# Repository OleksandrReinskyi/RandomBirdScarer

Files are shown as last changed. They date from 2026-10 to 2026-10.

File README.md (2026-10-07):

# Autonomiczny Stochastyczny Odstraszacz Ptaków

> Autor: Oleksandr Reinskyi
> 
## 1. Opis zasady działania
**Cel:** W gospodarstwie moich rodziców znajduje się plantacja leszczyny. Jednym z głównych zagrożeń dla orzechów są ptaki. Odstraszacze wykorzystujące pasywny czujnik podczerwieni okazują się nieskuteczne w warunkach sadu, z kolei inne rozwiązania są zbyt drogie. Dlatego właśnie powstał ten projekt. Opracowane urządzenie dąży do eliminacji zjawiska przyzwyczajania się szkodników do powtarzalnego dźwięku dzięki zastosowaniu sygnałów generowanych losowo.

System składa się z trzech głównych modułów:
1. **Moduł zasilania:** Pakiet 3 ogniw Li-Ion 3.7V
2. **Płytka stochastycznego kontrolera:** Układ analogowo-cyfrowy generujący losowe interwały załączania płytki generatora dźwięku.
3. **Płytka generatora dźwięku:** Układ wytwarzający falę prostokątną o częstotliwości 2,1–2,9 kHz, która trafia na glośnik.

Schemat blokowy systemu

W tym repozytorium znajduje się projekt płytki stochastycznego kontrolera.

---

### Zasada działania sterownika:

1. Dioda Zenera pracująca w stanie przebicia lawinowego generuje analogowy szum biały.
2. Niewielkie fluktuacje szumu są wzmacniane przez wzmacniacz operacyjny TL072 (wzmocnienie $A_u \approx 511$), a następnie przekształcane przez komparator LM393 na  ciąg impulsów, podawany na wejście danych $D$ przerzutnika typu D (HEF4013B).
3. * **Timer 1:** Generuje krótkie impulsy co 5 minut.
   * **Timer 2:** Odpowiada za taktowanie krótkich cykli dźwięku (co ok. 5–10 sekund)
4. Przebiegi z obu timerów są podawane przez diodową bramkę logiczną OR na wejście zegarowe $CLK$ przerzutnika.
5. Wyjście proste $Q$ steruje wejściem zerowania ($RESET$) Timera 2, decydując o zakończeniu lub wydłużeniu cyklu odstraszania.
6. Wyjście zanegowane $\overline{Q}$ steruje bramką tranzystora P-MOSFET, który załącza napięcie zasilania dla płytki generacji dźwięku.

Urządzenie załącza się w nieprzewidywalnych odstępach czasu będących wielokrotnością 5 minut (np. 5, 10, 15 min...) na losowy czas trwania będący wielokrotnością 10 sekund (np. 10, 20, 30 s...), co redukuję adaptację ptaków do sygnału. 

> **Uwaga:** Na potrzeby symulacji w LTspice oraz demonstracji wideo, wartości elementów $RC$ w generatorach czasowych zostały przeskalowane w dół, redukując okresy do odpowiednio **~20 s** (zamiast 5 min) oraz **~5 s** (zamiast 10 s)

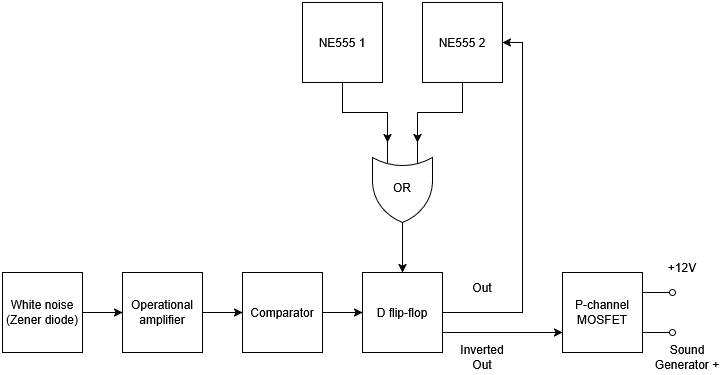
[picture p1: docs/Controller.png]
SchematIdeowy


---

## 2. Realizacja

### Wyniki symulacji (LTspice)
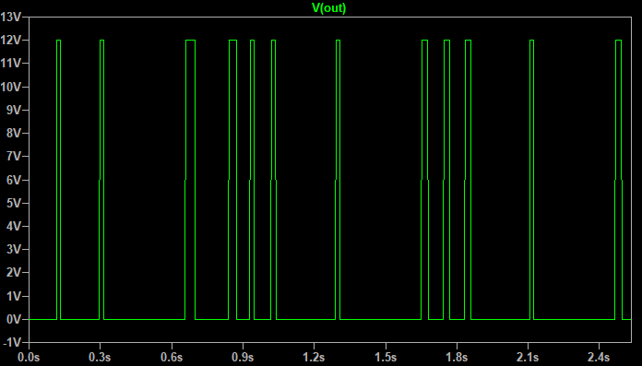
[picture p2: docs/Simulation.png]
Symulacja układu w LTspice


### Obudowa (FreeCAD)
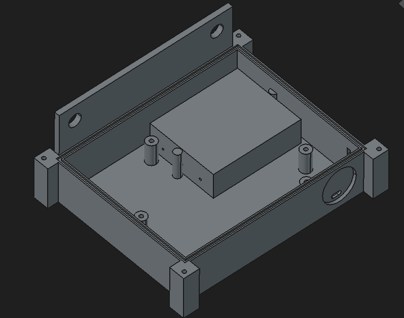
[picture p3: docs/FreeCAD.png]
Projekt obudowy w FreeCAD


### Demonstracja wideo
[Link](https://www.youtube.com/watch?v=rtPFrEMRT7Q)

### Zmontowany prototyp
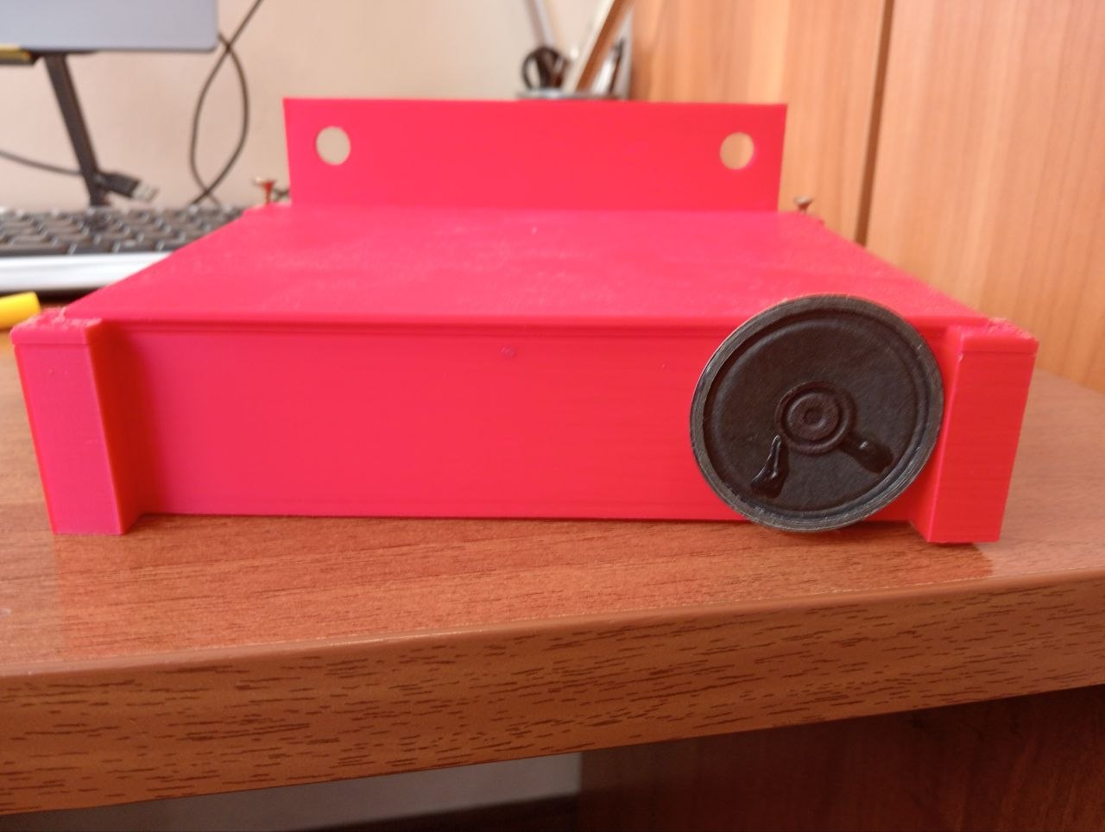
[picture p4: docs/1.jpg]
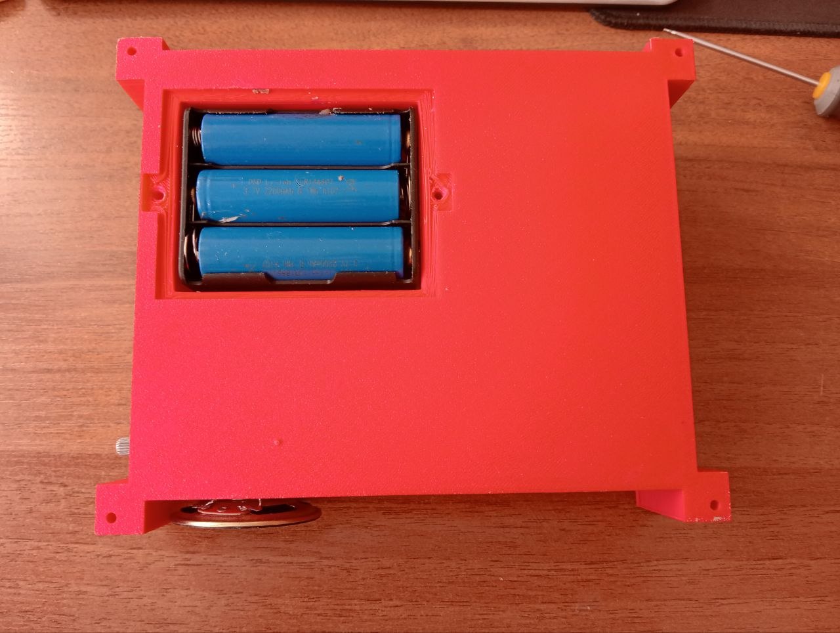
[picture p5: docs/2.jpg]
|  |  |
|--|--|
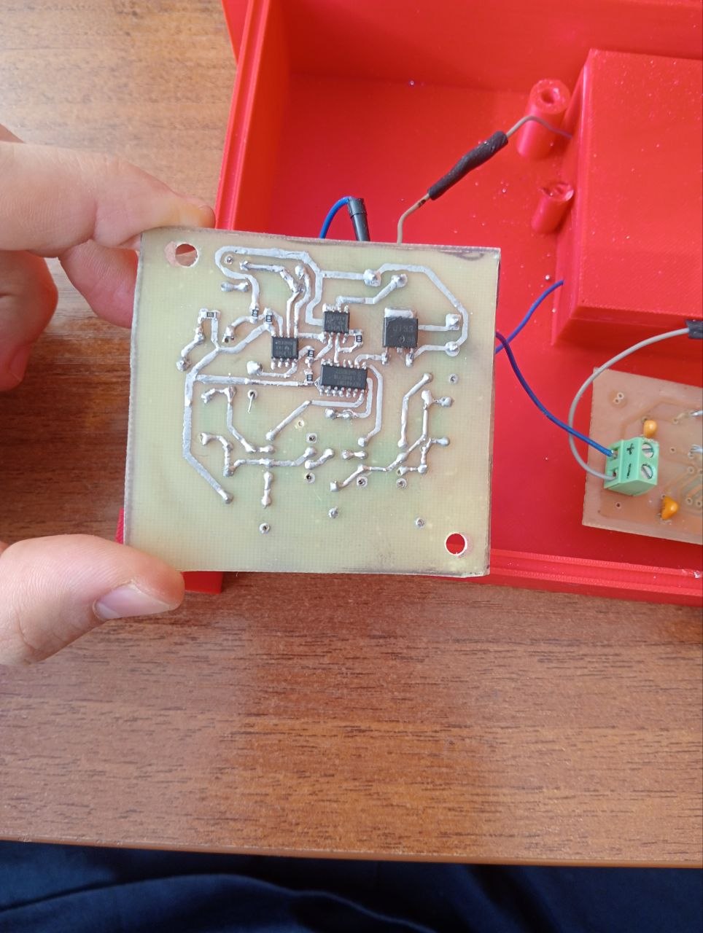
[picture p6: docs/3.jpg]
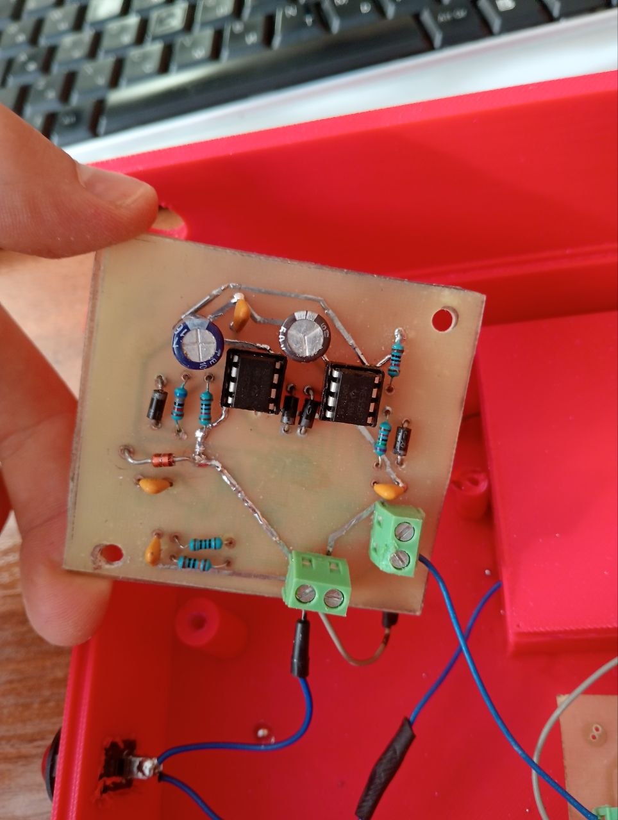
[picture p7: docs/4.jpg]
|  |  |

## 3. Problemy i napotkane trudności 

### Zidentyfikowane problemy:
* Brak hermetyczności obudowy. Wykonano ją z plastiku niskiej jakości i pozbawiono dedykowanych uszczelek.
* Ograniczony czas pracy. Zgodnie z obliczeniami urządzenie może pracować maksymalnie do 3 dni, po czym akumulatory wymagają ponownego naładowania. Również  brakuje modułu kontroli ładowania  (3S BMS)

### Napotkane trudności:
#### 1. Symulacja 
* Najpierw prowadziłem symulację stosując idealne modele elementów, co dawało wyniki niezgodne z rzeczywistością. Zamieniłem je na modele wybranych komponentów dla LTSpice.
* Najpierw nie stosowałem kondensatorów odsprzęgających i dlatego wzmacniacz ciągle wchodził w nasycenie. 
#### 2. Projektowanie płytki w KiCAD
* Jako PMOS użyłem najpierw symbolu o kolejności pinów DGS, a footprintu o kolejności pinów GDS, co spowodowało, że sygnał sterujący pojawiał się na Drain zamiast Gate.
* Nie zauważyłem, że LM393 ma otwarty kolektor i dlatego na wejściu Data HEF4013B zawsze było 0V.
* Na dolnej stronie płytki użyłem sterf wypełnionych miedzią jako węzłów dla +12v oraz GND. To sprawiło, że lutowanie lutownicą o małej mocy stało się niemożliwe, bo lut zastygał natychmiastowo.
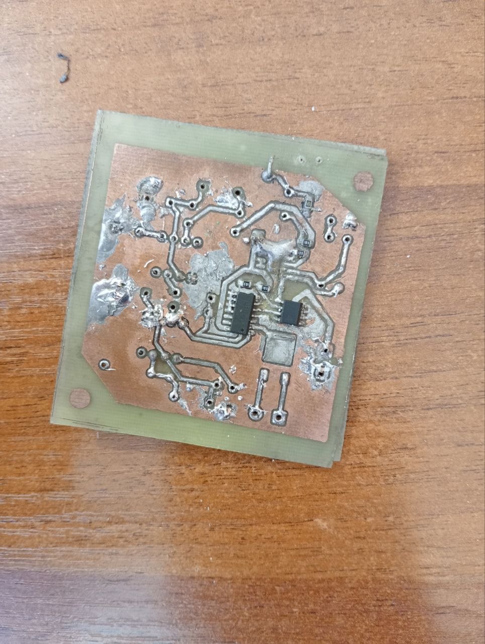
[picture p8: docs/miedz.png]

#### 3. Testowanie
* TL072 niedostatecznie wzmacniał sygnał z diody Zenera i dlatego komparator nie reagował na niego. Zwiększyłem wartości rezystorów, żeby wzmocnienie wynosiło około 500.
* Zauważyłem, że NE555 mocno się grzeją. Okazało się, że rezystory niedostatecznie ograniczały prąd płynący przez kondensator i dlatego tranzystor na pinie Discharge ciągle ulegał uszkodzeniu.

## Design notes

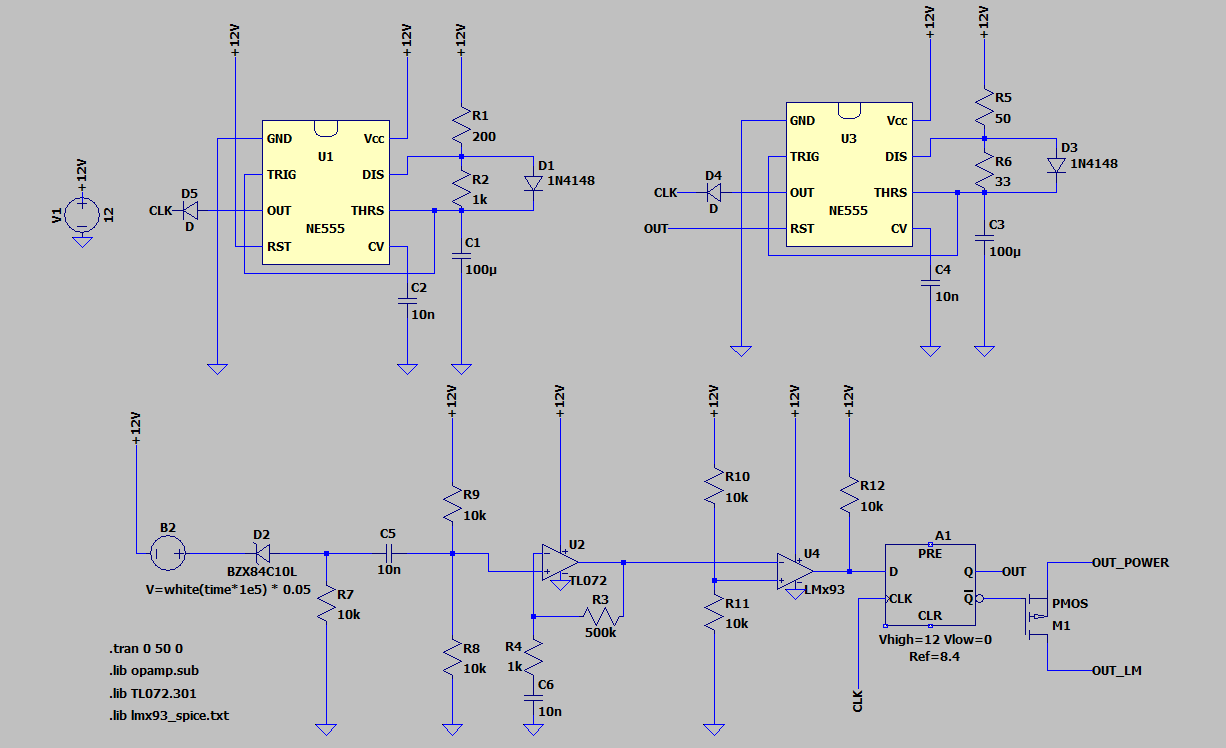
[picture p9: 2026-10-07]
docs/LTSPICE_scheme.png

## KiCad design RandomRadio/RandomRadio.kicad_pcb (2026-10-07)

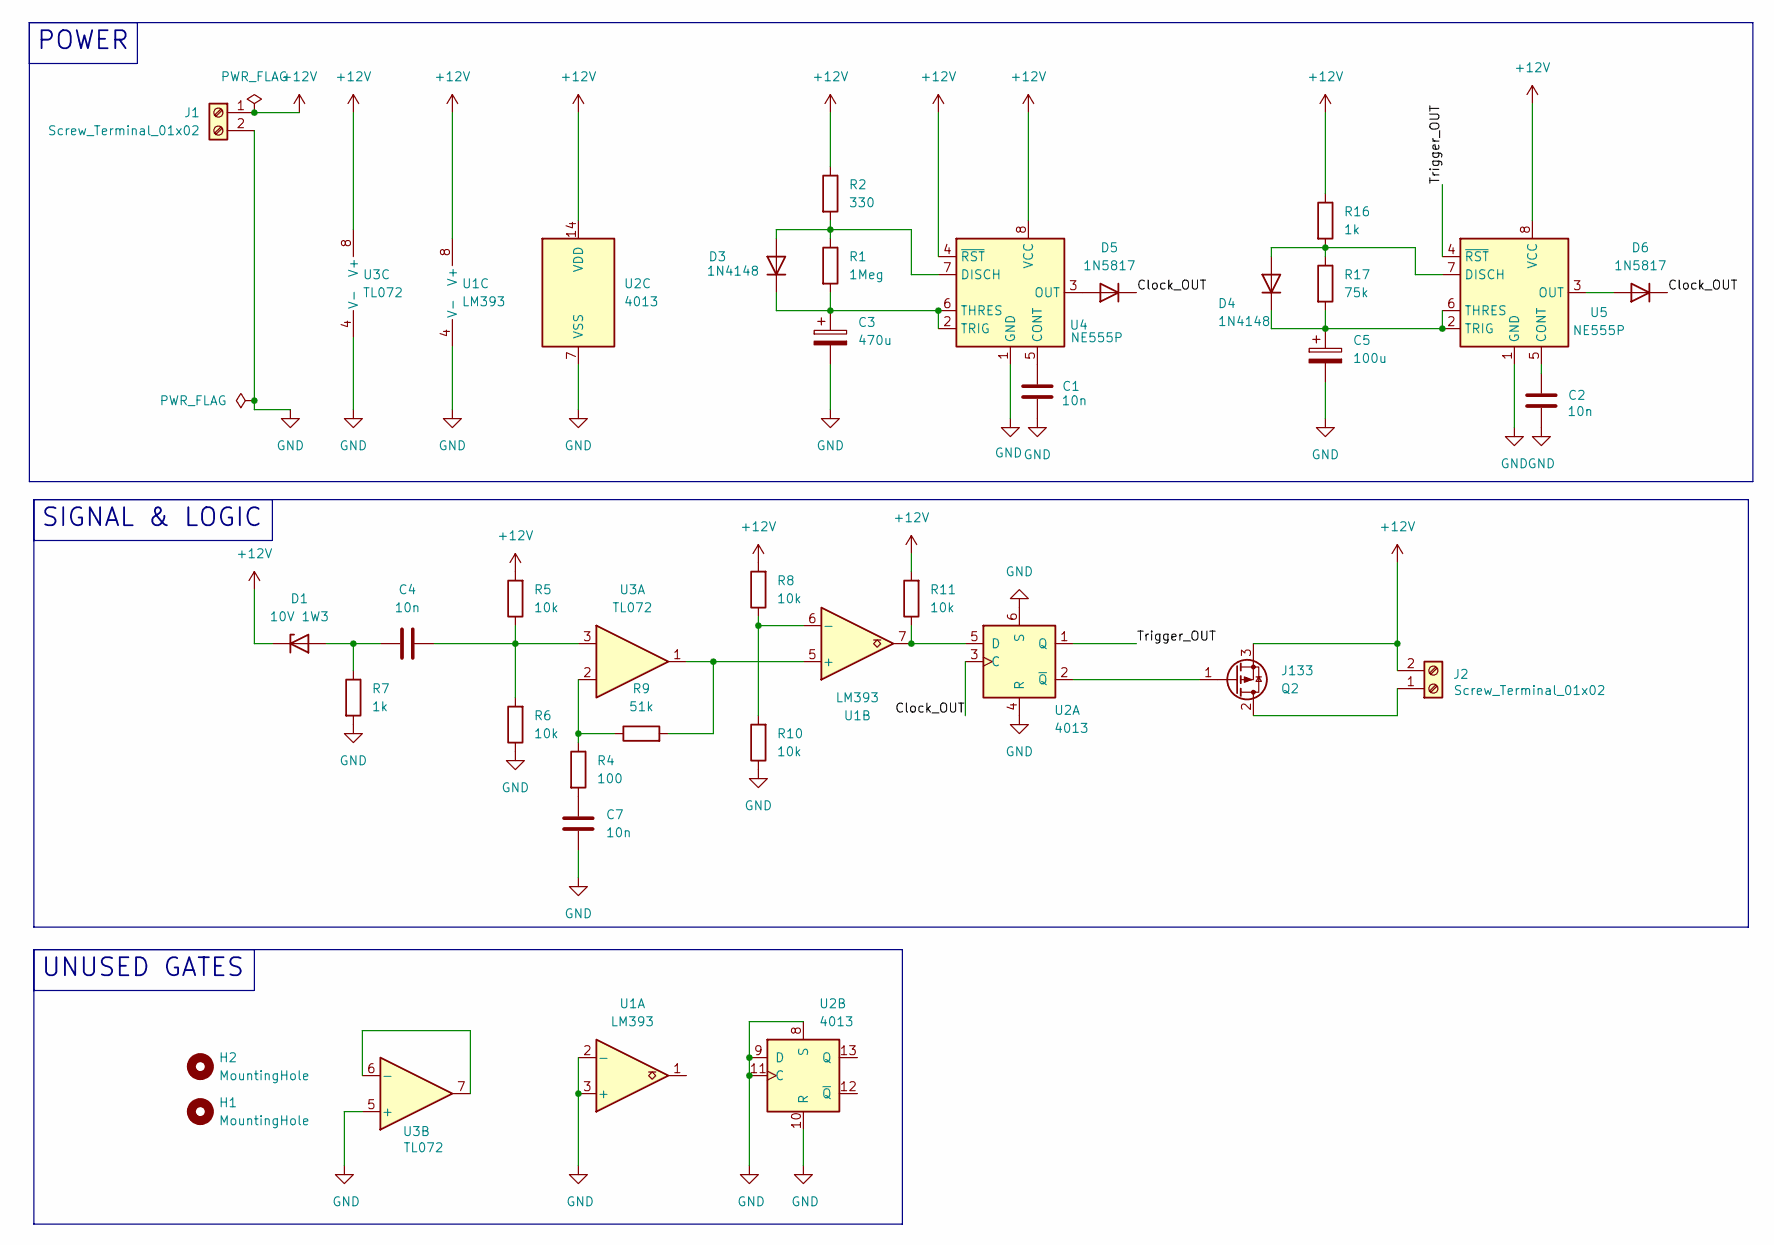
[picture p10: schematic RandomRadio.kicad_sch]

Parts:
C1, C2, C4, C7: 10n; C_Disc_D5.1mm_W3.2mm_P5.00mm
C3: 470u; CP_Radial_Tantal_D8.0mm_P5.00mm
C5: 100u; CP_Radial_Tantal_D8.0mm_P5.00mm
D1: 10V 1W3; D_DO-41_SOD81_P12.70mm_Horizontal
D3, D4: 1N4148; D_DO-35_SOD27_P7.62mm_Horizontal
D5, D6: 1N5817; D_DO-35_SOD27_P7.62mm_Horizontal
H1, H2: MountingHole; MountingHole_4.3mm_M4
J1, J2: Screw_Terminal_01x02; TerminalBlock_Phoenix_MKDS-1,5-2_1x02_P5.00mm_Horizontal
Q2: J133; TO-252-2
R1: 1Meg; R_Axial_DIN0207_L6.3mm_D2.5mm_P10.16mm_Horizontal
R2: 330; R_Axial_DIN0207_L6.3mm_D2.5mm_P10.16mm_Horizontal
R4: 100; R_Axial_DIN0207_L6.3mm_D2.5mm_P10.16mm_Horizontal
R5, R6, R8, R10, R11: 10k; R_0805_2012Metric_Pad1.20x1.40mm_HandSolder
R7: 1k; R_0805_2012Metric_Pad1.20x1.40mm_HandSolder
R9: 51k; R_Axial_DIN0207_L6.3mm_D2.5mm_P10.16mm_Horizontal
R16: 1k; R_Axial_DIN0207_L6.3mm_D2.5mm_P10.16mm_Horizontal
R17: 75k; R_Axial_DIN0207_L6.3mm_D2.5mm_P10.16mm_Horizontal
U1: LM393; SO-8_3.9x4.9mm_P1.27mm
U2: 4013; SO-14_3.9x8.65mm_P1.27mm
U3: TL072; SO-8_3.9x4.9mm_P1.27mm
U4, U5: NE555P; DIP-8_W7.62mm

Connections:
+12V: D1.1 (K), J1.1, J2.2, Q2.3 (S), R2.1, R5.2, R8.2, R11.2, R16.1, U1.8 (V+), U2.14 (VDD), U3.8 (V+), U4.4 (~RST), U4.8 (VCC), U5.8 (VCC)
/Clock_OUT: D5.1 (K), D6.1 (K), U2.3 (C)
/Trigger_OUT: U2.1 (Q), U5.4 (~RST)
GND: C1.1, C2.1, C3.2, C5.2, C7.1, J1.2, R6.1, R7.2, R10.1, U1.2 (-), U1.3 (+), U1.4 (V-), U2.4 (R), U2.6 (S), U2.7 (VSS), U2.8 (S), U2.9 (D), U2.10 (R), U2.11 (C), U3.4 (V-), U3.5 (+), U4.1 (GND), U5.1 (GND)
unnamed: C7.2, R4.2
unnamed: C4.1, D1.2 (A), R7.1
unnamed: D3.2 (A), R1.1, R2.2, U4.7 (DISCH)
unnamed: C3.1, D3.1 (K), R1.2, U4.2 (TRIG), U4.6 (THRES)
unnamed: D4.2 (A), R16.2, R17.1, U5.7 (DISCH)
unnamed: C5.1, D4.1 (K), R17.2, U5.2 (TRIG), U5.6 (THRES)
unnamed: D5.2 (A), U4.3 (OUT)
unnamed: D6.2 (A), U5.3 (OUT)
unnamed: J2.1, Q2.2 (D)
unnamed: Q2.1 (G), U2.2 (~Q)
unnamed: R9.2, U1.5 (+), U3.1
unnamed: R8.1, R10.2, U1.6 (-)
unnamed: R11.1, U1.7, U2.5 (D)
unnamed: C4.2, R5.1, R6.2, U3.3 (+)
unnamed: R4.1, R9.1, U3.2 (-)
unnamed: U3.6 (-), U3.7
unnamed: C1.2, U4.5 (CONT)
unnamed: C2.2, U5.5 (CONT)

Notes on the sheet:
UNUSED GATES
POWER
SIGNAL & LOGIC

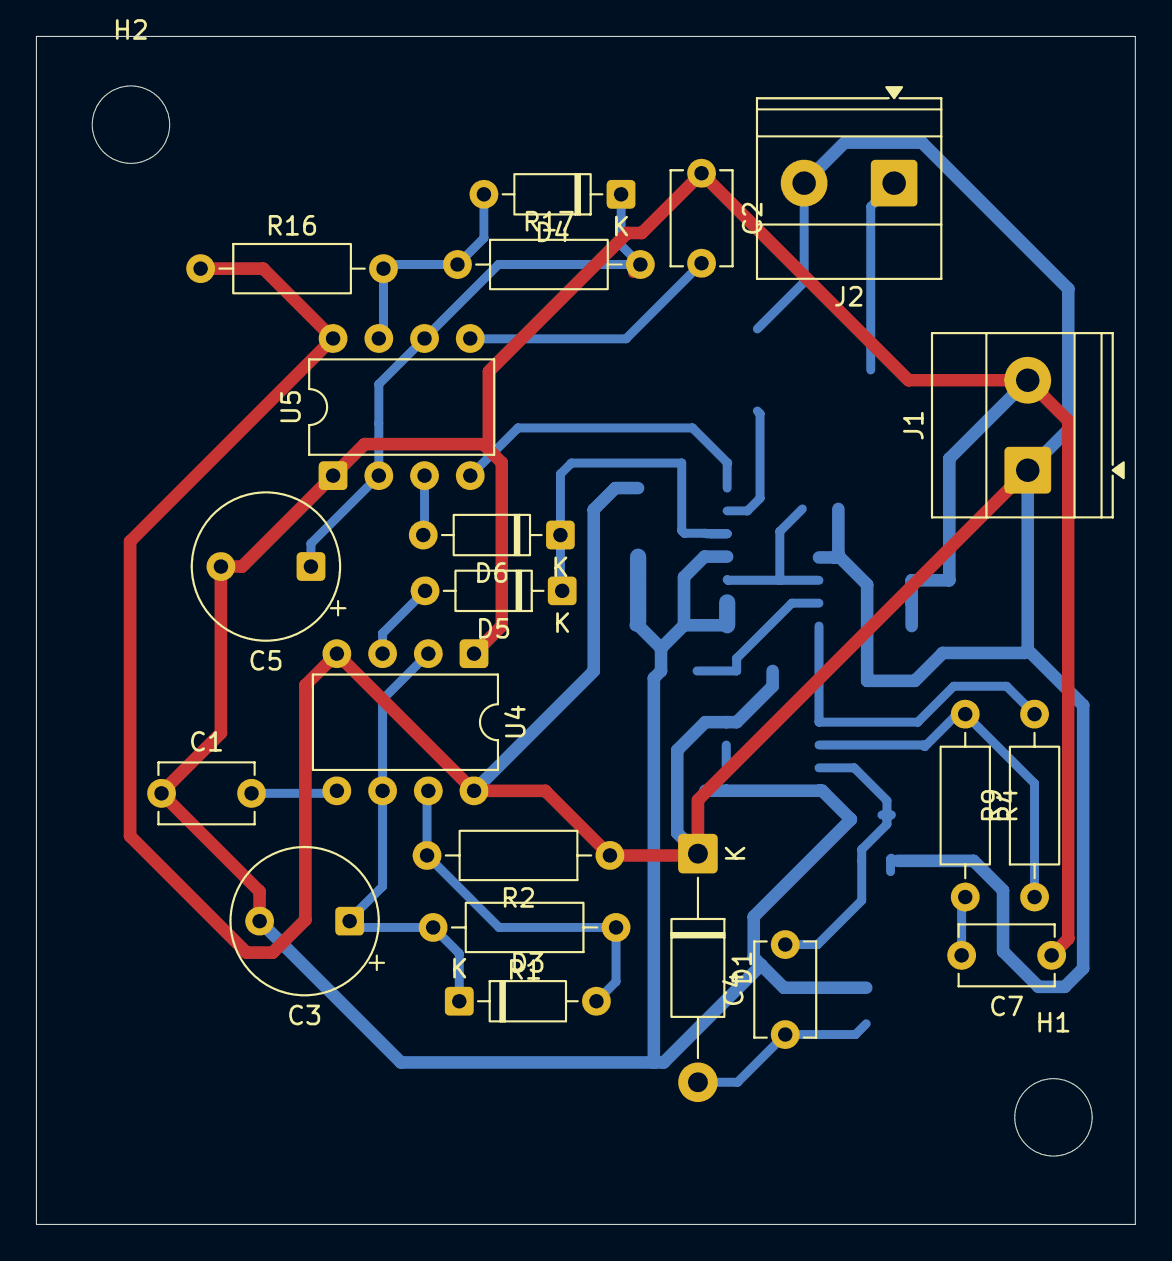
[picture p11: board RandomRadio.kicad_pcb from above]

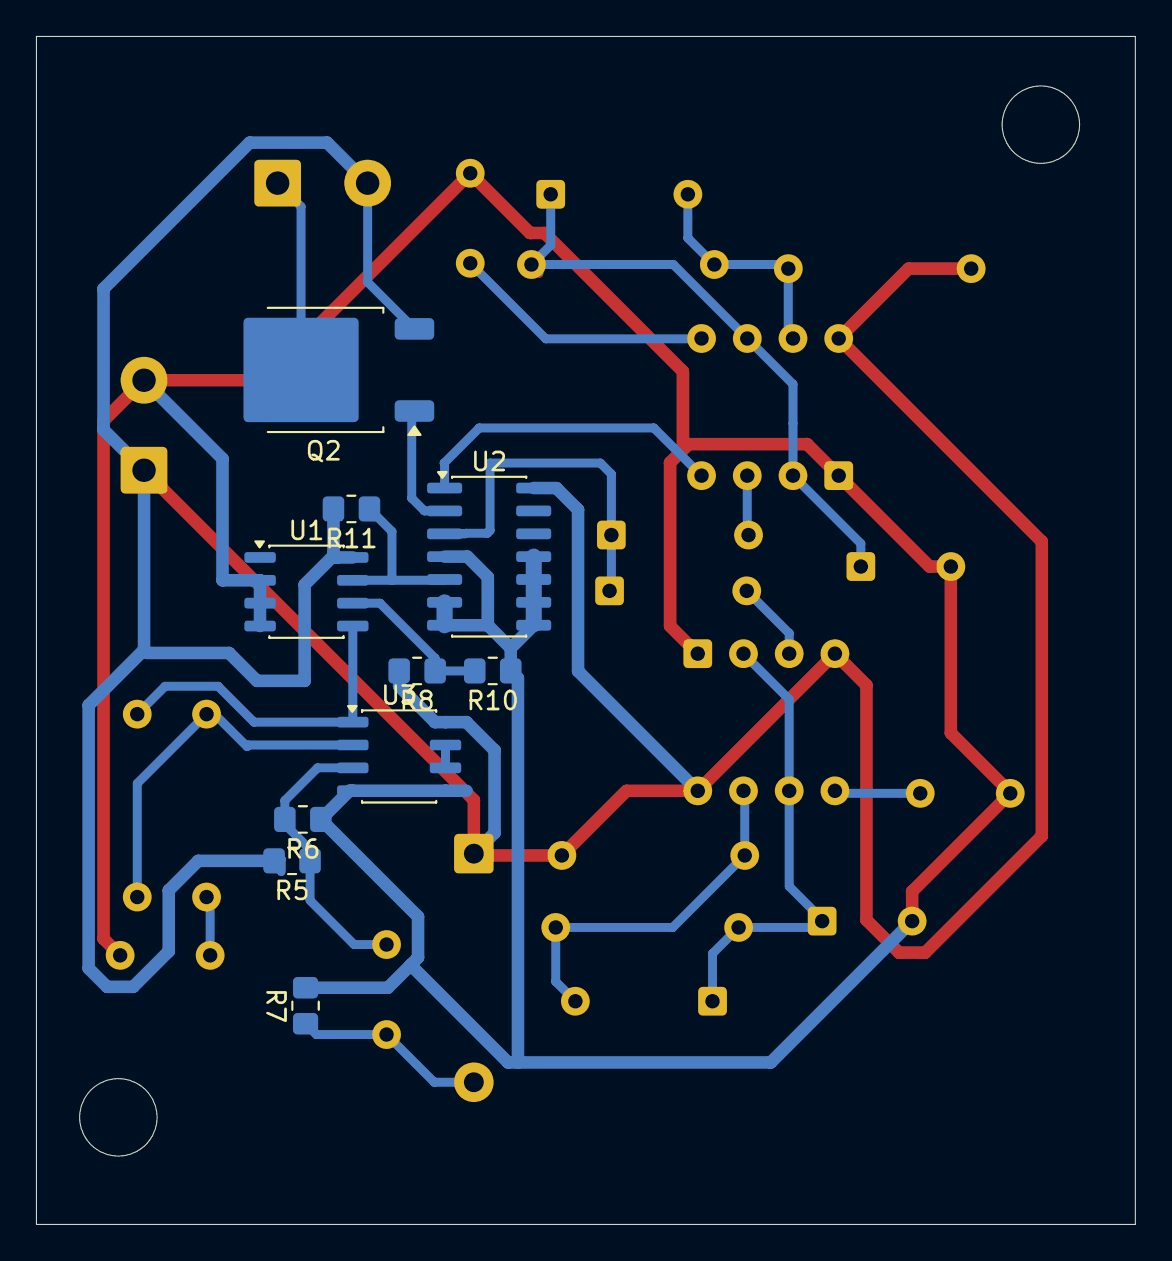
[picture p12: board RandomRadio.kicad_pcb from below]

Board: 2 copper layers, 61.0 x 66.0 mm, 33 parts (10 on the bottom side), 22 nets.
